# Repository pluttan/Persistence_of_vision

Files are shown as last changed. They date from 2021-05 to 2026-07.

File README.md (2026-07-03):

<div align="center">

# POVgram

**Persistence-of-vision LED cube 8x8x8 with a browser-based 3D animation editor**

</div>

A mechanical platform with a 64-LED WS2812B strip spins on a motor while an ESP32-S2 synchronizes color output with rotation, producing a volumetric 3D image of 512 virtual voxels in mid-air. Animations are created in a browser-based editor and uploaded to the device over Wi-Fi.

## ■ Features

- ❖ **512-voxel 3D display** — 8x8x8 POV cube rendered by a spinning 8x8 LED strip synchronized with a rotation sensor
- ❖ **Browser-based 3D editor** — React app with a Three.js live preview, per-slice pixel painting across XY/YZ/ZX planes, and undo/redo history
- ❖ **Multi-frame animation** — sequences of 8x8x8 frames with configurable rotation speed, looping, per-frame duplication, and drag-and-drop reordering
- ❖ **Custom color palettes** — 16-color palettes (default Catppuccin), saved across sessions via cookies, edited with a native color picker
- ❖ **Wi-Fi upload** — push animations to the device over HTTP as JSON, stored on SPI Flash (FAT), played back on demand
- ❖ **USB Mass Storage** — device appears as a USB drive (TinyUSB MSC) for direct file access to stored animations
- ❖ **PID motor control** — closed-loop speed regulation with hard-kickstart logic and fixed-point slider-crank layer-timing math

## ■ Stack

<div align="center">

| Component | Technology |
|---|---|
| MCU | ESP32-S2 |
| Firmware | ESP-IDF + FreeRTOS (C++) |
| LEDs | 64x WS2812B via SPI DMA |
| Layer timing | GPTimer (us reset) + fixed-point slider-crank math |
| Motor control | PID controller + LEDC PWM |
| Storage | SPI Flash (FAT via TinyUSB MSC) |
| HTTP server | esp_http_server (Wi-Fi STA) |
| Frontend | React 19 + Vite 7 |
| 3D visualization | Three.js (OrbitControls) |
| Default palette | Catppuccin |

</div>

## ■ How It Works

```
1. The rotation sensor fires a rising-edge interrupt; the ESP32-S2 uses fixed-point slider-crank math to compute precise per-layer timing offsets.
2. PID motor control (LEDC PWM) maintains stable rotation speed with hard-kickstart logic.
3. At each computed offset the firmware drives the 8x8 WS2812B strip via SPI DMA, painting one vertical slice of the current animation frame — building the full 8x8x8 voxel volume in mid-air.
4. Animations are authored in the browser editor: frames are painted slice-by-slice on XY/YZ/ZX planes and previewed live in a Three.js 3D view with undo/redo support.
5. The finished animation is exported as JSON and pushed to the device over HTTP (Wi-Fi); the device stores it on SPI Flash (FAT) and plays it back on demand.
6. The same Flash partition is also accessible as a USB Mass Storage drive (TinyUSB MSC) for direct file management.
```

## ■ Screenshots

<div align="center">



*Main animation editor interface with 3D cube preview*

</div>

## ■ Usage

### Frontend (animation editor)

```bash
cd povgram-frontend
npm install
npm run dev
```

### Firmware

```bash
cd usb-example/tusb_msc
idf.py set-target esp32s2
idf.py menuconfig    # set WIFI_SSID and WIFI_PASSWORD
idf.py build flash
```

### Upload Animation

1. Open the web editor in a browser
2. Draw frames slice by slice in the 8x8 grid, preview the cube in 3D
3. Enter the device IP in the badge, then open the Export menu and flash the animation to the device
4. Trigger playback from the same menu to display it on the cube

## ■ Repository Structure

```
POVgram/
├── povgram-frontend/             # React web editor (Vite)
│   └── src/
│       ├── components/
│       │   ├── MagicCube.jsx     # Main orchestrator / layout
│       │   ├── Cube3D/           # Three.js 3D preview
│       │   ├── panels.jsx        # LayerEditor, Palette, FrameTimeline, ExportMenu, ...
│       │   ├── ui.jsx            # Logo, ToolDock, ZNav, DeviceBadge, ...
│       │   ├── VoxelThumb.jsx    # Frame thumbnail renderer
│       │   ├── Onboarding.jsx    # First-run overlay
│       │   └── Toast.jsx         # Toast notifications
│       ├── hooks/
│       │   ├── useFrameAnimation.js  # Frame management + playback + undo/redo
│       │   └── usePaletteSystem.js   # Palette state + persistence
│       └── utils/                # device protocol, palette, voxel, persist
│
├── usb-example/tusb_msc/         # ESP32-S2 firmware (ESP-IDF)
│   └── main/components/
│       ├── init                  # task setup, sensor ISR, drawLayer
│       ├── wifi                  # Wi-Fi STA + HTTP API (esp_http_server)
│       ├── leds                  # WS2812B SPI driver + GPTimer
│       ├── pidController         # Motor speed regulation (PID + LEDC)
│       ├── PointsCalc            # Fixed-point slider-crank layer timing
│       └── usbMscStorage         # USB MSC + FAT filesystem
│
├── esp32c3-render-node/          # Experimental ESP32-C3 24x24x24 render node (SPI slave)
├── esp32c3-test-master/          # Experimental ESP32-C3 SPI-master test bench
└── demos/                        # Sample animations (JSON) + Node.js generators
```

## ■ Hardware

<div align="center">

| Part | Description |
|---|---|
| MCU | ESP32-S2 |
| LEDs | 64x WS2812B strip (data on GPIO 16, SPI2 @ 2.5 MHz) |
| Motor | DC motor + driver (LEDC PWM on GPIO 40, 2 kHz) |
| Sensor | Rotation sensor (GPIO 39, rising-edge interrupt, internal pull-up) |
| Storage | Internal SPI Flash (1 MB FAT partition) |
| Interface | USB (Mass Storage) + Wi-Fi (HTTP API) |

</div>

## ■ License

MIT © [pluttan](https://github.com/pluttan)

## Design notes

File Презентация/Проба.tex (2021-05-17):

\documentclass[10pt,pdf,hyperref={unicode}]{beamer}
\usepackage[T2A]{fontenc}
\usepackage[utf8]{inputenc}
\usepackage{movie15}
\setbeamertemplate{navigation symbols}{}
\usetheme{default}
\setbeamertemplate{background}{}

\definecolor{UniBlue}{RGB}{183,221,255}
\setbeamercolor{title}{fg=UniBlue}
\setbeamercolor{frametitle}{fg=UniBlue}
\setbeamercolor{structure}{fg=UniBlue}
\setbeamercolor{normal text}{fg=white}

\title{The title of presentation}   
\subtitle{Use beamer everywhere you are}
\begin{document}

\begin{frame}
\include{title}
\end{frame} 

\begin{frame}
\includemovie{1cm}{1cm}{ani.gif}
\end{frame}

\end{document}

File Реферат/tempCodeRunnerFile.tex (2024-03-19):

\vspace*{200px}
  \begin{flushright}
    Выполнил ученик 10 «А» класса\\
    Плютто Андрей Петрович\\
    Руководитель проекта\\
    учитель физики\\
    Горцакалян Жанна Степановна\\
  \end{flushright}

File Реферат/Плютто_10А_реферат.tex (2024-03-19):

\documentclass[a4paper, 12pt]{article}
\usepackage[T2A]{fontenc}
\usepackage[left=2cm,right=2cm,top=2cm,bottom=2cm]{geometry}
\usepackage[russian]{babel}
\usepackage{amsfonts,amsmath,amssymb}
\usepackage{mathrsfs}
\usepackage{graphicx}
\usepackage[normalem]{ulem}
\usepackage{wrapfig}
\usepackage{fancyhdr}
\usepackage{floatflt}
\usepackage{python}
\usepackage{indentfirst}
\usepackage{setspace}
\usepackage{scrextend}
\usepackage{listings}
\usepackage{makecell,tabularx}
\usepackage{hyperref}
\usepackage{xcolor}

\newcommand{\rub}{{\rm{Р}\kern-.635em\rule[.5ex]{.52em}{.04em}\kern.11em}}

\definecolor{linkcolor}{HTML}{000000} 
\definecolor{urlcolor}{HTML}{0000FF} 

\hypersetup{pdfstartview=FitH,  linkcolor=linkcolor,urlcolor=urlcolor, colorlinks=true}

\definecolor{grey}{RGB}{40, 40, 40}

\renewcommand{\href}[1]{\url{#1}}

\lstdefinestyle{CommentStyle}{
    language=XML,
    %numbers=left, numberstyle=\tiny, stepnumber=1, numbersep=5pt,
    commentstyle=\color{red},
	basicstyle=\footnotesize\ttfamily,
	language={[ANSI]C++},
	keywordstyle=\bfseries,
	showstringspaces=false,
	morekeywords={include, printf},
	commentstyle={},
	escapeinside=§§,
	escapebegin=\begin{russian}\commentfont,
	escapeend=\end{russian},
    keywordstyle=\color{blue}\bfseries,
    morekeywords={align,begin},
    extendedchars=\true,
    tabsize=2
}
\lstdefinestyle{myLatexStyle}{
    language=c++,
    %backgroundcolor=\color{grey},
    numbers=left, numberstyle=\tiny, stepnumber=1, numbersep=5pt,
    commentstyle=\color{red},
    keywordstyle=\color{blue}\bfseries,
    morekeywords={align,begin},
    extendedchars=\true,
    tabsize=2
}

\lstdefinestyle{pmyLatexStyle}{
    language=java,
    %backgroundcolor=\color{grey},
    numbers=left, numberstyle=\tiny, stepnumber=1, numbersep=5pt,
    commentstyle=\color{red},
    keywordstyle=\color{blue}\bfseries,
    morekeywords={align,begin},
    extendedchars=\true,
    tabsize=2
}

\setlength{\parindent}{12,5mm}

\onehalfspacing

\pagestyle{fancy}
\renewcommand{\sectionmark}[1]{\markright{#1}}
\fancyhf{} 
\fancyhead[R]{\bfseries\thepage}
\fancyhead[LO]{\bfseries\rightmark}

\newcommand{\image}[3]{
	\begin{figure}[ht]
		\center{ }
		\caption{\textit{#3}}\end{figure}
}
%\title{Проектная работа по теме:«Персистенция в реальной жизни»}

\newcommand{\cmd}[1]{\immediate\write18{#1}}
\newcommand{\pf}[1]{\immediate\input{#1}}
% \newcommand{\n}{ }
% \newcommand{\py}[1]{
% 	\cmd{
% 		k=''&&py=${k}&&n='exec("""def vip(l,k):\\n    for i in range(len(l)):\\n        try:\\n            if l[i]==";":i,k=i+1,k+("\\\\n")\\n            else: k+=l[i]\\n        except:break\\n    exec(k)\\n""");vip("""#1""".replace("|",chr(32)).replace(";"+chr(32),";"),"")'&&printf ${n// /|}>latex.py
% 		}
% 	\cmd{
% 		python3 latex.py>py.out 2>py.log
% 		}
% 	\pf{
% 		py.out
% 	   }
% 	}

\begin{document}
\thispagestyle{empty}
\begin{floatingfigure}{5.8cm}
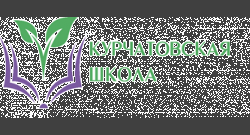
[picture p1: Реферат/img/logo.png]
  
  \vspace{0cm}
\end{floatingfigure}

\sloppy{
  \scriptsize{
    \line(6,0){0}

    \centering Департамент образования и науки города Москвы

    \centering ГОСУДАРСТВЕННОЕ БЮДЖЕТНОЕ

    \centering ОБЩЕОБРАЗОВАТЕЛЬНОЕ УЧРЕЖДЕНИЕ ГОРОДА

    \centering МОСКВЫ «КУРЧАТОВСКАЯ ШКОЛА»

    \line(6,0){300}

    \centering 123060, Москва, улица Маршала Конева, дом 10.

    \centering \textbf{Тел: (499) 194-10-44, E-mail: kurchat@edu.mos.ru}

    \line(6,0){0}
  }}

\topskip=-200pt
\vspace*{130px}
\begin{Huge}
  \textbf{
    \begin{center}
      Проектная работа по теме:\\«Персистенция в реальной жизни»
    \end{center}
  }
\end{Huge}
\vspace*{5px}
\begin{footnotesize}
  \center {В проекте был рассмотрен эффект персистенции зрения на примере сложного трехмерного опыта.
    В результате опыта получился один из видов голограмм: светодиодная голограмма.
    В рамках проекта также можно найти объяснение, применение и историю эффекта. }
  \vspace*{200px}
  \begin{flushright}
    Выполнил ученик 10 «А» класса\\
    Плютто Андрей Петрович\\
    Руководитель проекта\\
    учитель физики\\
    Горцакалян Жанна Степановна\\
  \end{flushright}
\end{footnotesize}
\begin{normalsize}
  \begin{center}
    Москва\\
    2021 год
  \end{center}
\end{normalsize}
\newpage
\thispagestyle{fancy}
\renewcommand{\sectionmark}[1]{\markright{#1}}
\fancyhf{}
\fancyhead[R]{\bfseries\thepage}
\fancyhead[LO]{\bfseries Оглавление}
\renewcommand{\contentsname}{Оглавление}
\small{\tableofcontents}
\newpage
\pagestyle{fancy}
\renewcommand{\sectionmark}[1]{\markright{#1}}
\fancyhf{}
\fancyhead[R]{\bfseries\thepage}
\fancyhead[LO]{\bfseries\rightmark}

\section{Аннотация}
Работа «Персистенция в реальной жизни» посвящена эффекту
персистенции зрения, наглядно представленному на примере сложного
трехмерного, иллюстрирующего этот любопытный феномен, опыта.
Понятие «персистенция зрения» (от лат. persisto - постоянно
пребывать, оставаться) иначе можно передать как «инерция зрения»,
многочисленные примеры которой были известны еще древним. Скажем,
если крутить горящий факел, человеческий мозг будет его
воспринимать — видеть — как огненный круг вместо ряда
последовательных положений одного и того же горящего факела,
ходящего по кругу. По сути, речь идет об иллюзии, значимость
которой отмечали еще древнеиндийские философы. Они утверждали,
например, что так называемая «человеческая личность»    - тоже
всего лишь похожий эффект «инерции умозрения». Иллюзия «личности»
видится нами как «единая целостность», как факельный круг, только
потому, что наш умственный взор не силах зафиксировать отдельные
точки движения человеческой души. На этом широком фоне понимания
сути данного эффекта интересно было представить конкретную краткую
историю его научного изучения, а также его объяснение и возможное
применение. Эти задачи выполнены на современном и технически
актуальном примере создания одного из видов голограмм: на примере
POV\footnote{\ POV -- Persistence of vision(персистенция зрения)}-голограммы.
\newpage
\section{Введение}
\subsection{Актуальность}
POV эффект мы можем наблюдать в реальной жизни каждый день.
Достаточно навести камеру телефона на электронные часы,
и мы сразу увидим частоту обновления кадров (FPS\footnote{FPS -- Frame-Per-Second(кадров в секунду)}).
То, что мы не видим это невооруженным глазом, объясняет POV эффект.
Поэтому POV является чуть ли не самым используемым эффектом анатомии человека.
\subsection{Проблема}
Потенциал персистенции зрения еще не раскрыт полностью. С помощью POV можно
создавать моментально не только 2D экраны, но и полноценные 3D голограммы.
\subsection{Цель работы}
Раскрыть потенциал POV, создать собственную голограмму из подручных средств.
\subsection{Задачи}
\begin{enumerate}
  \item Объяснить, как работает эффект
  \item Объяснить историю его открытия, историю его применения в физике
  \item Выяснить где эффект используется в наше время
  \item Создать собственную 3D поделку на основе данного эффекта
\end{enumerate}
\newpage
\section{Общие сведения о инерции зрения}
\subsection{Определение}
Персистенция зрения традиционно относится к оптической иллюзии,
которая возникает, когда зрительное восприятие объекта не прекращается
в течение некоторого времени после того, как исходящие от него лучи света
перестали попадать в глаз. Иллюзия также была описана как
"персистенция сетчатки", "персистенция впечатлений", просто "персистенция"
и другие варианты. Согласно этому определению, иллюзия будет такой же
или очень похожей на позитивные остаточные образы.

С момента своего появления термин "персистенция зрения" считается объяснением
восприятия движения в оптических игрушках, таких как фенакистископ и зоотроп,
а позже и в кино. Однако эта теория была оспорена еще до появления кинематографа
в 1895 году. Если " постоянство зрения "объяснить, как" слияние мерцания", то его
можно рассматривать как фактор иллюзии движущихся картинок в кино и связанных с ним
оптических игрушках, но не как ее единственный принцип.

Наиболее важным фактором в этом типе анимации является стробоскопический эффект,
подробно описанный изобретателем Саймоном Стампфером, но это было в значительной
степени проигнорировано теоретиками кино (по крайней мере, за пределами Германии и Австрии).

Ранние описания иллюзии часто объясняли этот эффект исключительно несовершенством
глаз, особенно сетчатки. Нервы и части мозга позже стали частью объяснений.
\subsection{Почему возникает?}

Эффект возникает при переполнении, перенасыщении палочек глаза.
Дело в том, что наш глаз состоит из палочек и колбочек: колбочки отвечают
за различие цветов, а палочки за насыщенность цвета. Когда цвет в
колбочках перенасыщается уже не можем различать один цвет от другого и
видим их все вместе.

\image{глаз.png}{170}{Строение человеческого глаза}

\newpage

\section{История POV}

Первое упоминание о персистенции зрения сделано Аристотелем
в 384-322 годах до н.э. Он первый отметил, что он наблюдает
солнечные лучи еще некоторое время после того как перестает
смотреть на них.

Открытие эффекта часто приписывают римскому поэту Лукрецию
(ок. 15 октября 99 г. до н. э.-ок. 55 г. до н. э.), хотя он лишь упоминает
нечто подобное в связи с образами, увиденными во сне.

Примерно в 165 году нашей эры Птолемей описал в своей книге
"оптика" вращающийся гончарный круг с нанесенными на него
различными цветами. Он отметил, как различные цвета секторов
смешиваются в один цвет и как точки появляются в виде кругов, когда
колесо вращается очень быстро. Когда линии рисуются поперек оси
диска, они заставляют всю поверхность казаться однородной по цвету.

"За зрительным впечатлением, созданным в первом обороте, неизменно
следуют повторные случаи, которые впоследствии производят
тождественное впечатление. Это также происходит в случае падающих
звезд, чей свет кажется расширенным из-за их скорости движения, все
в соответствии с количеством она проходит на ощутимом расстоянии
вместе с чувственным впечатлением, возникающим в зрительной
способности.

Порфирий (около 243-305) в своем комментарии к гармоникам
Птолемея описывает, что чувства не стабильны, а запутанны и неточны.
Определенные интервалы между повторными впечатлениями не
обнаруживаются. Белое или черное пятно на вращающемся конусе (или
вершине) выглядит как круг этого цвета, а линия на вершине
заставляет всю поверхность выглядеть в этом цвете. "Из-за быстроты
движения мы получаем впечатление линии на каждой части конуса,
когда линия движется."

В XI веке Ибн аль-Хайтам, который был знаком с трудами
Птолемея, описал, как цветные линии на волчке не могли быть
различимы как разные цвета, но появлялись как один новый цвет,
состоящий из всех цветов линий. Он сделал вывод, что зрению нужно
некоторое время, чтобы различить цвет. Аль-Хайтам также отметил,
что вершина казалась неподвижной, когда вращалась чрезвычайно
быстро, "поскольку ни одна из ее точек не оставалась неподвижной в
одном и том же месте в течение какого-либо ощутимого времени".

Леонардо да Винчи писал в своей записной книжке: "каждое тело,
которое движется быстро, кажется окрашивающим свой путь
впечатлением своего оттенка. Истинность этого положения видна из
опыта; так, когда молния движется среди темных облаков, скорость ее
извилистого полета делает весь ее путь похожим на светящуюся змею.

Таким же образом, если вы взмахнете зажженным клеймом, весь его
ход будет казаться кольцом пламени. Это происходит потому, что
орган восприятия действует быстрее, чем суждение."

Исаак Ньютон (1642-1726 / 27) якобы продемонстрировал, как
белый свет представляет собой комбинацию различных цветов с
вращающимся диском с цветными сегментами. При быстром вращении
цвета, кажется, смешиваются и кажутся белыми (или, скорее, не
совсем белым светлым оттенком). В его книге 1704 года оптики он
описал машину с призмами, линзой и большой движущейся гребенкой с
зубьями, вызывающими последовательное проецирование
чередующихся цветов. Если это делалось достаточно быстро, то
чередующиеся цвета уже не воспринимались отдельно, а
воспринимались как белые. Ньютон сравнил его принцип с эффектом
следа бенгальского огня: вращающийся горящий уголь может
выглядеть как круг огня, потому что, как он писал: «ощущение угля в
нескольких местах этого круга остается запечатленным на сенсориуме,
пока уголь снова не вернется в то же самое место.»

\image{круг.png}{200}{Ньютоновский опыт с кругом}
В 1768 году Патрик Д'Арси (1725-1779) сообщил, что он измерил
длительность 0,13 секунды для одного полного вращения горящего
угля, в то время как он рассматривался как полный круг света. Он
зарегистрировал несколько вращений специально построенной машины
в своем саду и в сотрудничестве с наблюдателем, который обладал
превосходным зрением (собственное зрение Д'Арси было повреждено в
результате несчастного случая). Д'Арси подозревал, что
продолжительность может отличаться у разных наблюдателей,
интенсивность света вращающихся объектов, цвета и расстояния
наблюдения. Он планировал дальнейшие эксперименты, чтобы
определить такие возможные различия, но, похоже, никаких
результатов опубликовано не было.

Будучи студентом университета, Джозеф Плато заметил в
некоторых своих ранних экспериментах, что при взгляде с небольшого
расстояния на два концентрических зубчатых колеса, которые быстро
вращаются в противоположных направлениях, создается оптическая
иллюзия неподвижного колеса. Позже он прочитал статью Питера
Марка Роже 1824 года и решил исследовать этот феномен дальше. Он
опубликовал свои выводы в Correspondance Mathématique et Physique
\footnote{\ Correspondance Mathématique et Physique -- Математическое и физическое соответствие}
в 1828 году и 1830 году. В 1829 году плато представил свой тогда еще
неназванный анортоскоп в докторской диссертации Sur quelques
propriétés des impressions produites par la lumière sur l'organe de la vue
\footnote{\ Sur quelques
  propriétés des impressions produites par la lumière sur l'organe de la vue --
  некоторых свойствах, производимых светом на зрение}.

\begin{figure}[ht]
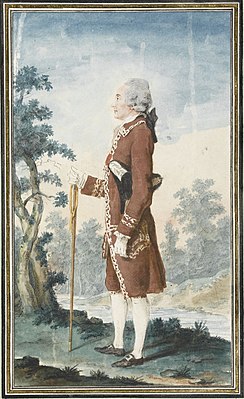
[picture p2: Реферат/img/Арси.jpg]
  \center{
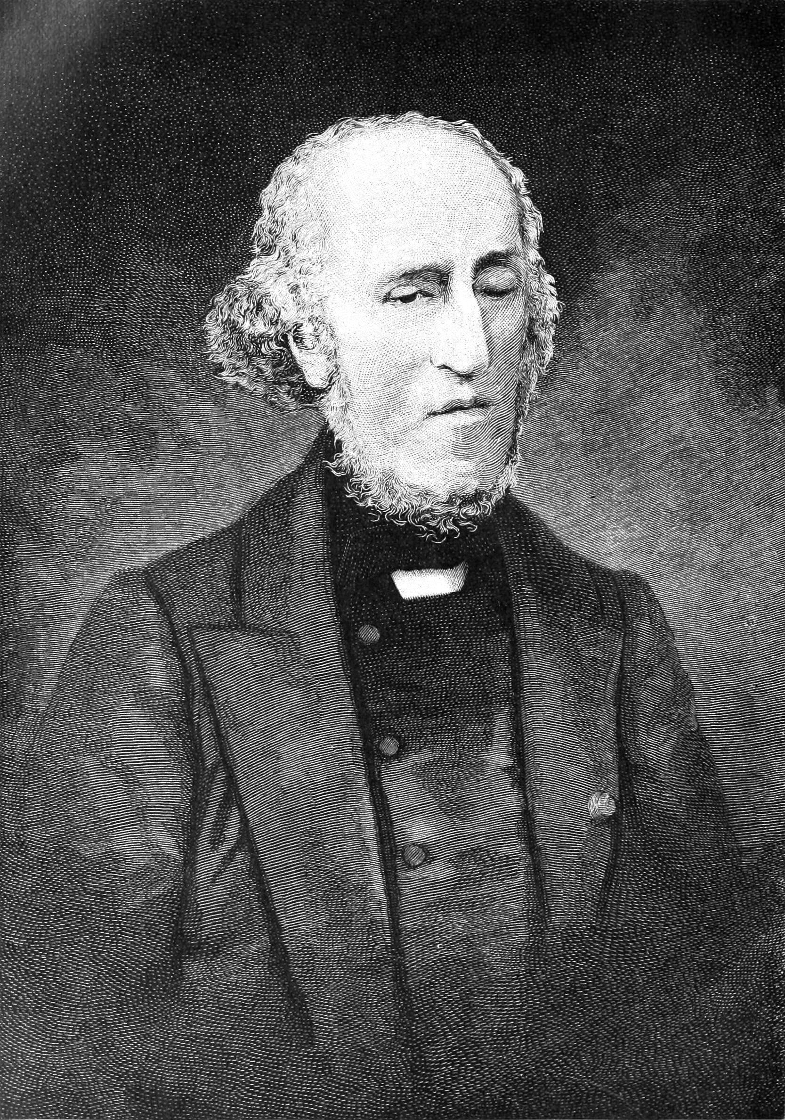
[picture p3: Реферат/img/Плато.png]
    }
  \caption{Слева -- \textit{Патрик Д'Арси}, Справа -- \textit{Джозеф Плато}}
\end{figure}

Анортоскоп представлял собой диск с анаморфным изображением,
которое можно было рассматривать как четкое неподвижное
изображение, когда диск вращался и просматривался через четыре
радиальные щели встречно вращающегося диска. Диски также могли
быть полупрозрачными и освещаться сзади через щели вращающегося
против часовой стрелки диска.

Далее был создан зоотроп, который оказался хорошей заменой
диску, описанному выше. «В зоотропе диск с отверстиями заменен
деревянным или металлическим барабаном, открытым сверху,
прорезанным вертикальными щелями по бокам и вращающимся
горизонтально на оси. Диск с картинками заменен длинной лентой,
которая помещается, свернутая в круг, внутри барабана. Эти ленты
могли вместить пять, десять и более дюжин картинок, тогда как диски
не могли вместить больше двух дюжин.» — Жорж Садуль. Вот мы и
подобрались от истории создания эффекта до использования этого
эффекта в реальной жизни.

\newpage

\section{Природные условия, объясняемые персистенцией}

\subsection{Молния}

При грозе люди обычно видят молнии как большой электрический
разряд из неба. На деле мы чаще всего видим траекторию движения –
остаточное изображение из-за очень яркого белого света.

\image{Гроза.jpg}{200}{След молнии на фоне темного неба}

\subsection{Снежные бури}
В снежную метель иногда становиться сложно увидеть, что
находиться даже в метре от вас. Это возникает не только от того что
одновременно падает огромное количество снежинок, но и от того, что
снежинки преломляют свет, и мы видим свет уже упавших снежинок,
как свет ещё падающих.

\image{Снег.png}{200}{Снежная метель}

\newpage

\section{Прямые использования эффекта}
\subsection{Тауматроп}

Таумотроп - это игрушка, основанная на оптической иллюзии: при
быстром вращении кружка с двумя рисунками, нанесенными с разных сторон,
они воспринимаются как один. Была особо популярна в Викторианскую эпоху.
Жорж Садуль утверждает, что создателем тауматропа является Джон
Гершелл. Ещё в 1824 году он поспорил со своим другом Чарльзом Беббиджем,
что сможет показать ему одновременно две стороны золотой гинеи. Он
вращал монету на ребре, а Беббиджа попросил поместить глаз на её уровне.
Обе стороны монеты слились воедино.

В 1825 Генри Фиттон и доктор Пари, популяризируя этот опыт, превратили
его в детскую игрушку, получившую имя тауматроп.

\image{Пингвин.jpg}{220}{Таумотроп с пингвином в шаре}

\subsection{Анортоскоп}

Анортоскоп — аппарат изобретённый в 1828 году брюссельским
физиком Жозефом Плато.

Анортоскоп состоял из двух дисков: прозрачного, помещённого сзади, и
непрозрачного помещённого впереди и имевшего отверстия. Оси дисков,
находились рядом, но не совпадали и которые приводились во вращение
вокруг одной и той же оси, во взаимно противоположном друг другу
направлении и с различными скоростями. Передний непрозрачный круг
снабжен вырезами, на заднем же, прозрачном и освещаемом помещенной
позади его свечкой, находится рисунок, который, будучи наблюдаем сквозь
щели переднего круга во время вращения кругов, появляется при известном
отношении скоростей вращения обоих кругов.

Анортоскоп создавал впечатление, как говорил Плато: «точного изображения
гиперболы, проходящей через два центра вращения». Позже он заменял одну
из линий рисунками, таким образом получая искаженное изображение вместо
правильной линии.

\image{С мышкой.jpg}{200}{Анортскоп, вышитый 13-летним мальчиком для школьного проекта}

\thispagestyle{fancy}
\renewcommand{\sectionmark}[1]{\markright{#1}}
\fancyhf{}
\fancyhead[R]{\bfseries\thepage}
\fancyhead[LO]{\bfseries Прямые использования эффекта}
\subsection{Фенакистископ и стробоскоп}
Фенакистископ — лабораторный прибор, конструкция которого
основана на персистенции, способности сетчатки человеческого глаза
сохранять изображения. Изобретателем фенакистископа является Жозеф
Плато. Почти одновременно с Плато Симон фон Штампфер изобрел аппарат,
очень похожий на фенакистископ и назвал его «стробоскопом». Является
более совершенным анортоскопом.

\image{Фенакистископ.jpg}{220}{Обычный фенакистископ}

\subsection{Зоотроп}
Я уже упоминал зоотроп в истории создания персистенции, так что
пришло время рассмотреть это подробнее.

Зоотроп — устройство, конструкция которого основана на персистенции,
способности сетчатки человеческого глаза сохранять изображения.

Изобретателем зоотропа является Уильям Джордж Хорнер. Зоотроп является
трансформацией фенакистископа Жозефа Плато.

Современный зоотроп был изобретен в 1833 году британским математиком
Уильямом Джорджем Хорнером. Сам он назвал свое изобретение «дедалеум»
или «колесо дьявола». В 1860 году француз Дезвинь, и американец Уильяма Е.
Линкольн закрепили за всеми подобными устройствами название «зоотропа».

В 2008 году компания Sony создала зоотроп в виде тора диаметром 10 метров
и 10 тонн весом. Внутри находится второй тор, представляющий собой
большое количество выгнутых экранов. Внутренний тор вращается с
окружной скоростью 44 км/ч (и может разгоняться свыше 50 км/ч). На экранах
же появляется высокочёткое изображение.

Зоотроп был занесён в книгу рекордов Гиннесса, как самый крупный в мире.
(Посмотреть на него можно будет в презентации)

\image{зоотроп.jpg}{250}{Чертеж одного из первых зоотропов в мире}

\newpage

\subsection{Кинеограф}

Кинеограф— приспособление для создания анимированного
изображения, состоящего из отдельных кадров, нанесённых на листы бумаги,
сшитые в тетрадь. Зритель, перелистывая особым способом тетрадь,
наблюдает эффект анимации. Кинеография является одной из форм
мультипликации.

Название кинеограф запатентовано в 1868 году англичанином по имени Джон
Бернс Линнет. В 1894 году пионер кинематографа Макс Складановски
использует кинеограф для просмотра своих первых пробных съёмок.

В 1897 году англичанин Генри Уильям Шорт наладил массовое производство
кинеографа под патентованным названием филиоскоп, снабдив его
металлическим футляром и рычагом, облегчающим перелистывание страниц.

\image{Кинеограф.jpg}{300}{Нарисованный кинеограф}

\subsection{GIF}

GIF — растровый формат графических изображений. Способен хранить
сжатые данные без потери качества в формате не более 256 цветов. Не
зависящий от аппаратного обеспечения формат GIF был разработан в 1987
году (GIF87a) в фирме CompuServe для передачи растровых изображений по
сетям. В 1989-м формат был модифицирован (GIF89a): были добавлены
поддержка прозрачности и анимации). Долгое время GIF был одним из
наиболее распространённых форматов в интернете. GIF позволяет соединять
и демонстрировать в виде видео отдельные фотографии.
\newpage
\section{Косвенные использования эффекта}
\pagestyle{fancy}
\renewcommand{\sectionmark}[1]{\markright{#1}}
\fancyhf{}
\fancyhead[R]{\bfseries\thepage}
\fancyhead[LO]{\bfseries\rightmark}

\subsection{Кадровая частота}

Кадровая частота используется в абсолютно всех экранах и мониторах,
это специальная величина которая измеряет сколько кадров монитор покажет
в секунду. Когда монитор показывает много кадров мы видим целое, не
склеенное видео. Тут инерция зрения возникает как косвенный эффект. Как
интересный факт стоит отметить то что до 1922 года инерция зрения
считалась основным эффектом зрения, который используют в фильмах, но
затем было доказано обратное.

\image{Медведь.jpg}{80}{Один шаг анимированного медведя (покадрово)}

Дополнительные примеры: Электронные часы, электронные
билборды, видео.

\subsection{POV пропеллер}

И вот мы подобрались к самому интересному: POV механизмы. Каждый
из нас замечал на детских праздниках светящиеся пропеллеры. Они состоят
из простого мотора и нескольких светодиодов. Дело в том, что если
посмотреть на этот пропеллер со стороны науки, то он опережает свое время.
Он не только дает красивый зрительный эффект, но и преображает
одномерную полоску светодиодов в двумерный рисунок. Впоследствии
именно это стало отправной точкой моего продукта.

\image{пропеллер.jpg}{200}{POV пропеллер}

\newpage

\section{Практическая часть}
\vspace{-7px}
\subsection{Введение в практическую часть}

Любой проект начинается с идеи. Мой проект тоже начался с идеи.
Точнее с одной идеи и огромного количества предположений по возможной реализации продукта.
Что-бы как-то объединить все соображения в один продукт я набросал список, того,
что понадобится для физической реализации голограммы:
\vspace{-7px}
\begin{enumerate}
  \item Кривошипно-шатунный механизм
        \vspace{-10px}
  \item Мотор
        \vspace{-10px}
  \item Светодиоды
        \vspace{-10px}
  \item Управление системой
        \vspace{-10px}
\end{enumerate}
\subsubsection{Кривошипно-шатунный механизм}

Кривошипно-шатунный механизм(КШМ) предназначен для преобразования
возвратно-поступательного движения поршня во вращательное движение
(например, во вращательное движение коленчатого вала в двигателях
внутреннего сгорания), и наоборот. Детали КШМ делят на две
группы, это подвижные и неподвижные детали:

Подвижные: поршень с поршневыми кольцами, поршневой палец,
шатун, коленчатый вал с подшипниками или кривошип, маховик.

Неподвижные: блок цилиндров (является базовой деталью двигателя
внутреннего сгорания) и представляет собой общую отливку с картером,
головка цилиндров, картер маховика и сцепления, нижний картер (поддон),
гильзы цилиндров, крышки блока, крепежные детали, прокладки крышек
блока, кронштейны, полукольца коленчатого вала.

Конечно это общее определение и устройства КШМ. Мне КШМ нужен для того,
чтобы привести платформу со светодиодами в движение.

\image{Шатун.png}{230}{Устройство КШМ}

\newpage

На Рис.13 изображена примерная модель моего шатунного механизма
Как видно он состоит из 4 деталей:
\vspace{-7px}
\begin{enumerate}
  \item Крепление 1 шатуна к мотору
        \vspace{-10px}
  \item 1 шатун
        \vspace{-10px}
  \item 2 шатун
        \vspace{-10px}
  \item Крепление 2 шатуна к платформе
        \vspace{-10px}
\end{enumerate}
Точками BMT и НМТ обозначены самое высокое
положение платформы и самое низкое соответственно.
Между ними расстояние S к которое я вычислю позже.
Шатунный механизм получилось сделать достаточно просто
из маленького кусочка орг-стекла и пару отрезков проволоки.

\subsubsection{Мотор}

Понятно, что шатунный механизм надо привести в движение
при помощи мотора.
Сначала я подумал реализовать мотор без каких-либо затрат,
с помощью дрели и крепежей, но затем я нашел неплохой вариант
мотора из СССР.

\image{Мотор.jpg}{250}{Мотор}

Крутящиеся части у него с 2 сторон, поэтому можно сделать целых 2 шатунных механизма
с одной и другой стороны. Питание может происходить от розетки без адаптеров питания.
В начале проекта это было довольно удобным дополнением, но затем пришлось помучаться
(см. 8.4.3).

\newpage
\subsubsection{Светодиоды}

Светодиоды -- самая главная часть моего продукта
изначально идея заключалась в том, чтобы сделать маленькую
матрицу из RGB\footnote{\ RGB -- red green blue(красный зеленый синий)} светодиодов.

\image{Светодиод.png}{140}{RGB светодиод}

На картинке видно, что у каждого светодиода есть 4 ножки. Если на первую подать
плюс а на вторую минус, то загорится красный цвет. Если на третью подать
плюс а на вторую минус, то загорится зеленый цвет. Если на четвертую подать
плюс а на вторую минус, то загорится синий цвет.

\begin{figure}[ht]
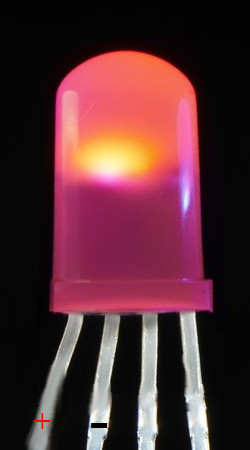
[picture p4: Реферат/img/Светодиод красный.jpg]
  \center{ }
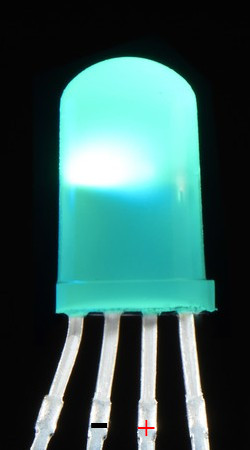
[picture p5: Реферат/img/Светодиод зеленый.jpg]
  
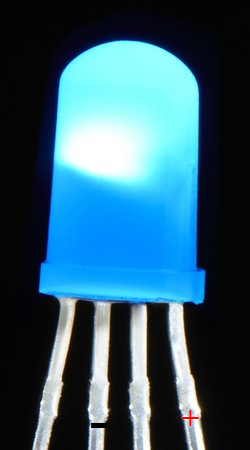
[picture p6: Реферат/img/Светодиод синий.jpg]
  
  \caption{\textit{RGB светодиод, горящий красным, зеленым и синим цветом}}
\end{figure}

И так теперь у нас есть 3 цвета: красный, зеленый, синий.
Теперь смешаем цвета: из красного и синего получим фиолетовый,
из красного и зеленого -- желтый, из зеленого и синего -- голубой.
Если соединим все три ножки, то получим белый.
И так у нас есть практически вся палитра радуги(за исключением оранжевого)
и белый цвет. При всех этих обстоятельствах я подавал ток с фиксированным напряжением
3V. Но производители заявляют, что на RGB светодиоды можно подать от 2,1V до 3,3V но
как можно было догадаться если мы будем подавать ток с меньшим напряжением, то светодиоды
будут гореть тускло, а с большим ярко. В аналоговых входах моего МК
\footnote{\ МК -- микроконтроллер(подробнее в 8.1.4)}
напряжение можно подавать деля его на десятые. Таким образом получаем, что у
нас есть есть 23 напряжения и 7 цветов для каждого напряжения. Вычислим
количество цветов и оттенков К, которые мы можем получить $$K=23!\times
  7\thickapprox 1,8*10^{23}$$ Конечно мы не увидим каждый из оттенков и они нам
попросту не нужны в настолько большом сегменте. Возьмем общепринятое количество
оттенков каждого цвета -- 256. Тогда для того, что-бы запрограммировать 1
светодиод нам понадобится передать коду L значений. Вычислим L: $$L=256\times
  256\times 256= 16777216 \thickapprox 1,6*10^7$$ Ученые-биологи пока доказали,
что человек может воспринимать около 10 миллионов ($10^7$) цветов, поэтому для
школьного проекта такой палитры цветов будет более чем достаточно.

Это все начальные данные о светодиодах, которые необходимо знать не только для
того,чтобы понять, но и для того, чтобы повторить проект.

\subsubsection{Микроконтроллер}

Из текста о светодиодах можно было понять, что для управления ими нужен
источник питания источником питания может служить простой адаптер для зарядки
гаджетов, но тогда, что-бы включить или выключить светодиод нам придется
совершать определенные механические действия. Но человечество давно изобрело
процессоры, которые помогают из несложного набора единиц и нулей начать или
прекратить подачу энергии на определенные участки пути. Конечно, использовать
голый процессор в моем проекте было бы сложно и не очень нужно: ведь процессору
нужна и память, и программатор, и ядро, написание которого может занять годы.

Поэтому предлагаю вашему вниманию список, состоящий из названий микросхем в
корпусе которых это объединено:

\begin{enumerate}
  \item   Микрокомпьютер
  \item   Компьютер
  \item   Микроконтроллер (МК)
\end{enumerate}

Давайте поподробнее разберем все 3 варианта и в конце, сопоставив все, выберем
самый лучший. Для этого я составил таблицу, которая показывает 3 главных
аспекта: кол-во портов, память и удобство программировать.
\begin{center}
  \begin{small}
    \begin{tabular}{ |c|c|c|c|c|}
      \hline
      Название   & Определение            & Кол-во портов & Память(ГБ) & Программирование        \\ \hline

      Микро-     & Семейство компьютеров, & 12-46         & 8-256      & удобные среды           \\
      компьютер  & которые в отличии      &               &            & разработки              \\
                 & от других компьютеров  &               &            & непосредственно         \\
                 & работают на            &               &            & в микрокомпьютере       \\
                 & RAM-архетиктуры.       &               &            &                         \\ \hline

      Компьютер  & Здесь: система,        & 2-8           & 256-2048   & Практически нету        \\
                 & имеющая полноценный    &               &            & открытых средств        \\
                 & процессор, способный   &               &            & разработки, все команды \\
                 & выполнять миллиарды    &               &            & по управлению USB       \\
                 & операций в секунду     &               &            & можно осуществить       \\
                 &                        &               &            & только через терминал   \\\hline

      Микро-     & Микрокомпьютер         & 12-56         & до 1       & среда разработки        \\
      контроллер & с урезанным            &               &            & Arduino idle            \\
                 & функцианалом           &               &            &                         \\
      \hline
    \end{tabular}
  \end{small}
\end{center}
Давайте разберемся по порядку: я беру микроконтроллер для удобства его
программирования также у него должно быть достаточное кол-во портов для
подключения всей электроники, о которой речь пойдет позже, так что компьютер,
не смотря на его большую вычислительную мощность не подходит.

Так же мне ни к чему покупать микрокомпьютер т.к. с таким проектом может
справится сравнительно небольшой микроконтроллер. На нем я и остановился, а
именно на модели Arduino NANO.

\image{дуня нано2.jpg}{140}{Arduino NANO}

Пусть на такой микроконтроллер провода нужно будет припаивать, но по моему
опыту это один из самых удобных МК из всех. Так же следует отметить, что
Arduino NANO - уменьшаная копия Arduino UNO, так что в последствии я буду
использовать обе модели для наглядности, разницы между ними нет. На Рис. 17
представлена распиновка (последовательность входов и выходов МК). Стоит
отметить, что даже на таком маленьком микроконтроллере я не использую все
выходы, а лишь несколько цифровых (помеченных надписью Dig).

\image{дуня нано.jpg}{150}{Распиновка Arduino NANO}

\subsubsection{Светодиодная матрица}

А теперь перейдем к решению вопроса, который я старательно обходил в 8.1.3:
если у светодиода 4 ножки, то ему понадобится 4 пина?

Да это так, а т.к. мой продукт должен состоять не из одного светодиода, а
как минимум 4, то их ножки займут все 12 цифровых выходов(+) и 1 землю(-).
Но голограмма 4$\times$4$\times$4 будет слишком маленькой. В идеале размеры
голограммы должны составлять 16$\times$16$\times$16. Но тогда ножек у
светодиодов будет $16*16*3=768$, что в 64 раза больше, чем есть у меня на
плате, и в 15 раз больше, чем на самом большом МК, который подается сегодня.

Рассмотри RGB ленту:Начнем с того, что в обычной светодиодной ленте, все светодиоды ленты
питаются и светятся одновременно, поскольку все они получают питание
параллельно от одного источника, драйвера, который работает по своему алгоритму, реализуемому
непосредственно внутри драйвера, и просто подает питание сразу на всю ленту, по сути - на все
параллельно подключенные к нему светодиоды.

Адресная светодиодная лента, в отличие от обычной, содержит так называемые адресные
светодиоды. Это значит, что каждый светодиод хотя и получает питание параллельно от
общего источника, включается каждый светодиод по индивидуальной команде, и значит,
на каждом светодиоде можно получить собственный уникальный оттенок, один из 16581375
возможных(см.8.1.3).

Каждый светодиод в адресной ленте имеет свой уникальный адрес, по которому
драйвер обращается к нему при помощи трехбитной команды. Команды отправляются в
линию последовательно, для этого служит третий на ленте провод «DATA INPUT».

\image{лента.jpg}{80}{Распиновка адресной ленты}

Возле каждого светодиода на адресной ленте установлен свой микрочип.
Каждый чип имеет три выхода — каждый на свой цвет, вход передачи данных,
выход передачи данных, вывод питания, вход установки режима и общий вывод.

Каждый RGB-светодиод на самом деле имеет в себе три светодиода (красный,
зеленый и синий), поэтому для управления одним сегментом (один сегмент — это
RGB-светодиод с чипом) требуется 3 байта информации, один байт — один цвет.

Каждый байт может принимать одно из 255 значений, поэтому в принципе каждый
RGB-светодиод способен дать свет одним из 16581375 оттенков. Количество байт
в одной команде равно таким образом 3 умножить на количество последовательных
рабочих сегментов в ленте. Конечно можно передавать ленте каждый раз по 3
значения, но я думаю, что удобнее всего будет передать ей один цвет в формате
hex(16-битный формат представления цвета, где каждый цвет кодируется 2
символами).

%Но как можно было понять что-бы сделать из ленты матрицу надо разрубить 256
%светодиодную ленту на 16 кусочков по 16 светодиодов, а затем соединить их
%последовательно.

\image{лента в тинкеркад.png}{180}{Макет адресной марицы, созданный мной}

\newpage

\subsection{Корпус}
И так мы определили все, что нужно для реализации продукта.
теперь надо подумать как это все компактно уместить под крышку
одного корпуса.
\subsubsection{Размеры}
Конечно сначала нужно поговорить о размерах корпуса,ведь принцип
чем больше - тем лучше я думаю не подходит. И так структурируем каждую
деталь корпуса. Стоит отметить, что под корпусом я подразумеваю только
неподвижные детали, о шатунном механизме, моторе и других деталях я
напишу позже.

Хочется отметить, что на этот момент у меня уже есть все вещи, которые описаны
в 8.1, поэтому я могу совершенно спокойно снять все замеры именно с них.
Внимательно изучив все полученные данные я понял, что платформа, на которую
будет крепится сама модель должна быть размером 16$\times$22, что-бы на ней
поместилась матрица и дополнительные крепления. К слову матрицу я сделал не
сам, как первоначально задумывал, а купил в китае, т.к. цена на ленту с таким
же количеством светодиодов была даже выше, чем цена на матрицу(подробнее 8.8.3)

Далее изучив размер мотора, я понял, что коробка корпуса должна быть высотой в
20см. Таким образом я набросал примерный план некоторых деталей для статической
части корпуса.
\\
\begin{center}
  \begin{tabular}{ |c|c|c|c|c|}
    \hline
    Номер  & Количество & Материал & Размеры(мм)             \\
    детали & деталей    &          &                         \\
    \hline
    1      & 2          & фанера   & 220$\times$200$\times$5 \\
    \hline
    2      & 3          & фанера   & 160$\times$200$\times$5 \\
    \hline
    3      & 4          & брус     & 20$\times$200$\times$10 \\
    \hline
    4      & 4          & стальной & 320$\times$8            \\
           &            & стержень &                         \\
    \hline
  \end{tabular}
\end{center}

\newpage
\subsubsection{Детали 1-2}

Первые две детали будут образовывать коробку, в которой будет находится
электроника и шатунный механизм. Вы, наверное, заметили, что вторых деталей
я сделал в количестве трех штук. Я сделал их именно столько для использования
внутренней перегородки о которой я рассажу позже. Изначально я хотел сделать
эти детали из гипсокартона. Но он оказался слишком рассыпчатый и я решил
выбрать другой материал. В качестве другого материала я взял хороший лист
фанеры и наметил все 5 деталей.

\image{разметка фанеры.jpg}{200}{Разметка фанеры}

Потом начался процесс выпилки. Пилить такое дерево можно практически абсолютно
всем начиная от фрезы заканчивая ручной пилой.Я выбрал относительно легкий
вариант -- электролобзик. Им достаточно легко пилить и получается относительно
маленькая погрешность: всего 0,3мм. Выпилил я все за один зимний вечер и
получилось все с первого раза.

\image{разметка фанеры.jpg}{200}{Выпиленные детали}

\newpage
Дальше начался процесс сборки. Он состоял в том, что надо было разметить  Он был
относительно сложным, т.к фанера имела маленькую ширину.
При вворачивании очередного самореза фанера сломалась. Тогда
я понял, что нужно все переделывать и делать дополнительные подпорки для
каждого угла фанеры.

\subsubsection{Дополнительные подпорки (3-я деталь)}

Для изготовления подпорок я выбрал брус, длиной 2 метра, который я распилил
на 4 кусочка по 20см каждый. Затем я соединил их с 4-ыми деталями и вот, что
получилось:

Конечно можно было мучиться с уголками, но брус выполнял еще одну немаловажную
роль для продукта -- в нем можно было установить держатели для подложки.

\subsubsection{Держатель подложки (4-я деталь)}

Чем я и занялся. Дело в том, что прутья, которые я хотел купить не продают
настолько маленьких размеров, так что за идеально ровными прутьями мне пришлось
ехать на другой конец города -- на металлолом.

Но как можно видеть на фото из этого вытекает целых 2 проблемы: первая, что
прут покрыт ржавчиной, вторая, что он один и большой -- значит прийдется
пилить.

С первой проблемой справился довольно быстро: воду и перекись смешиваем в
пропорции $\frac{2}{1}$ и добавляем лимонную кислоту 100 грамм на 200 мл
перекиси. Оставляем так на час и ржавчины нет.

Со второй проблемой пришлось помучаться: сталь плохо пилится ручной пилой,
а пилы по железу для лобзика у меня нету. В начале я распилил прут на 4 части
по 32 см, но затем оказалось, что это слишком много и прут пришлось подпиливать
после установки.

\subsubsection{Сборка}

Сборка прошла на удивление гладко, в два этапа.

В первый этап я просверлил отверстие в детали 3 диаметром 8 мм, затем
начал забивать деталь 4 в деталь три.

\image{Одна деталь.jpg}{160}{Деталь 4 в детали 3}
\newpage

Далее я повторил свю эту операцию еще три раза. Самое сложное было просверлить
отверстие идеально ровно под углом $90^{\circ}$.

\image{4 детали.jpg}{250}{4 готовых детали}
Осталось прикрутить все вместе. Вот полученный результат:

\image{Получившаяся_конструкция.jpg}{230}{Результат}
\newpage

\subsection{Динамические детали корпуса}

После моего долгого повествования о том, как было сложно сделать корпус
поговорим о еще более важных вещах: закрепление мотора на его месте, пайка
всех проводов и закрепление распределительной коробки рядом с мотором.

Думаю, что для вас это покажется самой скучной часть из всего моего
повествования, так что постараюсь уменьшить ее.

\subsubsection{Мотор}

Для мотора была подготовлена деталь и я подробно рассказывал о её изготовке
в главе 8.2.2. Сама деталь технически представляет собой пятую стенку, которая
разделит уже имеющееся пространство в коробке на 2 параллелепипеда.

В ней я проделал большую дырку и вставил туда мотор. Закрепил его 2 стержнями
горячего клея и прикрутил 4 уголка.

Далее, наметив место для уголков, я закрепил панель в корпусе, предварительно
подняв на нужную высоту.

\subsubsection{Панель и пол}

Панель я решил сделать из оргалита\footnote{прессованный картон, ДВП}.
Получилось даже аккуратно. После я купил линейные подшипники и сделал 4 дырки
для них.

После я сделал небольшую подставку под оптический датчик и пол для закрепления
распределительной коробки.
\subsubsection{Шатун}

Немного посоветовавшись с руководителем моего проекта я понял , что меньший
шатун должен быть 80мм, а наибольший 140мм. Делать шатуны я решил из орк-стекла
с запасом в 10мм. Я взял болты диаметром 3мм и, сделав из металлического листа
держатель, закрепил шатун на его месте.

\subsubsection{Распределительная коробка}

В распределительной коробке я решил сделать ардуино и все провода, ведущие и
исходящие из неё. Но, принявшись за дело, я решил, что к коробке будет трудно
подобраться после склейки корпуса, так что я впаял туда еще ардуино и
аккумулятор.

Вместе с аккумулятором пришлось добавить переключатель и плату для зарядки
аккумулятора.

После я закончил пайку и залил все горячим клеем, который выступил в роли
диэлектрика.

После собрал все в одну коробку и предлагаю вам ознакомиться с доп.
улучшениями, которые я сделал для следующих версий. Хоть в программировании я
это не описал, но все улучшения я подключил и запрограммировал.

\subsection{Дополнительные технические улучшения}

\subsubsection{Щелевой оптический датчик}

Конечно многие могли заметить то, что я избегаю сложных вычислительных
задач в этом проекте и не очень хочу заниматься некоторыми расчетами. Это все
верно, но с помощью оптического датчика можно решить достаточно много проблем
которые могут возникнуть при работе с проектом. Во-первых неравномерность
шатунного механизма. Нетрудно догадаться, что под силой притяжения шатун будет
быстрее спускаться, чем подниматься. Во-вторых могут возникнуть проблемы
в прорисовке и картинка будет сбиваться. В-третьих вычислительная мощность МК
маленькая и все ОЗУ во время прорисовки будет заполнено, так что решать
проблему путем физических вычислений по любому не получится. Тут на помощь
приходит датчик движения. Но не простой. Дело в том, что скорость передачи
датчиков очень мала. Она мала настолько, что просто не возможно что-либо
передать МК на больших скоростях, которые я планирую развить. Поэтому я буду
использовать щелевой датчик движения(щелевой оптический датчик) из названия
которого можно понять, что радиус его поля всего лишь щель.

В данный датчик состоит из лазера и фотоэлектрического датчика: лазер постоянно
светит через через щель, а фотоэлектрический датчик принимает его свет и
выдает нули, если фотоэлектрический датчик перестает принимать свет т.е. между
ним и лазером возникает препятствие, то датчик передает единицы. В нашем случае
препятствие -- нижнее положение шатуна. Таким незамысловатым образом я могу
где находится шатун в определенный промежуток времени.

\image{Датчик.jpg}{130}{Датчик, спаянный и закрепленный на платформе}

\newpage
\subsubsection{Светодиоды}

Для понимания состояния МК я решил добавить на корпус зеленый и желтый
светодиод.\\
\textbf{$\text{Зеленый}$}

Зеленый светодиод я планирую использовать в 2 режимах: первый когда он
горит это означает, что плата работает, прорисовка запущена. Второй когда он
мигает это означает, что плата готовится к запуску. Стоит отметить, что если
светодиод мигает слишком долго -- это означает, что плата не смогла произвести
калибровку и/или возникла ошибка при запуске мотора(см.8.4.3).

\image{Зеленый.jpg}{150}{Зеленый светдодиод}
\textbf{$\text{Желтый}$}

Желтый светодиод будет гореть при всех остальных проблемах и мигать, если будет
загрузка на плату.

\image{Желтый.jpg}{150}{Желтый светодиод}
\newpage

\subsubsection{Реле для мотора}

Реле в моем проекте играет довольно большую роль. Как я говорил в 8.1.2
чтобы связать мотор и МК так, что МК будет управлять мотором нужно реле.

\image{Реле.jpg}{200}{Реле}

Реле -- автоматический переключатель, который может переключить даже маленькая
сила тока. Предлагаю разобраться в его устройстве подробнее:

\image{реле устройство.jpg}{200}{Устройство реле}

Реле представляет собой катушку, состоящую из немагнитного основания, на
которое намотан провод из меди с тканевой или синтетической изоляцией, но чаще
всего с диэлектрическим лаковым покрытием. Внутри катушки установленной на
нетокопроводящее основание, размещается металлический сердечник. Также в
устройстве имеются пружины, якорь, соединительные элементы и пары контактов.

При подаче тока на обмотку электромагнита (соленоида) сердечник притягивает
якорь, который соединяется с контактом и электрическая или электронная цепь
замыкается. При снижении силы тока до определенного значения, якорь, под
действием пружины, возвращается на исходную позицию, вследствие чего
происходит размыкание цепи.

Более плавная и точная работа достигается благодаря использованию резисторов,
а защиту от скачков напряжения и искрения обеспечивает установка конденсаторов.
У большинства электромагнитных реле имеется не одна, а несколько пар
контактов, что позволяет управлять несколькими цепями одновременно.

Далее мы будем говорить о самом важном аспекте моего продукта --
программировании. Но перед тем, как я приступлю рассказывать, я хочу отметить,
что в этой и последующих главах встречается программный код. Оформил я его так:
слева идет код, а справа комментарии и пояснения.

Первым делом я решил запрограммировать матрицу.\newpage
\subsection{Программирование матрицы}
Первый код дался мне довольно легко: всего неделя изучений и улучшений. Предлагаю
вашему вниманию первый рабочий код для светодиодной матрицы.
\begin{flushright}\begin{huge}\textcolor{grey}{Arduino}\end{huge}\end{flushright}
\begin{tabular}{c p{180px}}
  \hline
  \begin{lstlisting}[style=myLatexStyle]
#include "Adafruit_NeoPixel.h"
const uint32_t AR[16][256] PROGMEM = 
#define PIN 13        
#define NUM_LEDS 256   
Adafruit_NeoPixel strip = Adafruit_NeoPixel(
    NUM_LEDS, PIN, NEO_GRB + NEO_KHZ800);
void setup() {
    strip.begin();
    strip.setBrightness(50);    
    strip.clear();                          
    strip.show();                           
	}
void loop() {
    for (int i1 = 0; i1 < 16; i1++){
			for (int i = 0; i < 256; i++){
				strip.setPixelColor(i,
					pgm_read_word(&AR[i1][i]));
				};
			strip.show();
			delay(100);
		};
	}
\end{lstlisting}
   &
  \begin{tabular}{p{180px}}
    Импортируем библиотеку           \\
    Задаем массив данных             \\
    Описываем переменную порта       \\
    Описываем переменную для свет.   \\
    Описываем переменную библиотеки
    на которой управляется матрица   \\
    Начинаем ф-цию установки         \\
    Начинаем общение с матрицей      \\
    Устанавливаем яркость(0-255)     \\
    Очищаем матрицу(заливаем черным) \\
    Показываем результат заливки     \\
    Заканчиваем установку            \\
    Начинаем постоянную ф-цию        \\
    Берем цикл для слоев             \\
    Берем цикл для светодиодов       \\
    Устанавливаем значение
    текущего светодиода              \\
    Заканчиваем цикл светодиодов     \\
    Показываем слой                  \\
    Ждем 100мс                       \\
    Заканчиваем цикл слоев           \\
    Повторяем постоянную ф-цию       \\
  \end{tabular} \\
\end{tabular}

\newpage
\subsubsection{Почему  Adafruit NeoPixel(ст. \#1)}

Для начала предлагаю разобрать все возможные варианты управления матрицами:
через библиотеки и на прямую. Я думаю, что и вам и мне выбор сразу очевиден --
пойти не через библиотеки, т.к. они занимают много ОЗУ и мало для чего будут
нужны. Но тут не все так просто. Пойдя вторым способом я наткнулся на огромное
количество подвисаний с которыми не собирался сталкиваться.

Вывод очевиден: оказывается библеотеки ко всему прочему оптимизируют программу
не давая ей повода зависать. Тут перед нами открывается еще один выбор:
использовать fastLED -- вроде как более универсальную, но новую, не изученную
библиотеку или старую NeoPixel от компании Adafruit. Думаю по моей работе можно
смело заявить, что я не ищу легких путей, поэтому я принялся "грызть"
документацию по fastLED. Но вот прошло некоторое время и наступили каникулы.
Моя семья и я уехали отдыхать и доступа к Arduino у меня не было, но я не
отчаялся и использовал приложение Tinkercad в котором не было матрицы и я её
сделал собственными руками. Результат работы можно посмотреть на Рис. 20.
И тут возникла еще одна проблема: в Tinkercad нету поддержки fastLED, зато
старушка NeoPixel подключается и работает спокойно. Вот так я, перепробовав
кучу вариантов, выбрал самый неочевидный для себя. Под конец программирования
вся среда разработки выглядела так:

\image{Среда.png}{80}{Среда разработки}

\newpage

\subsubsection{Работа с данными (ст. \#2)}

Если вы думали, что тут пойдет лучше -- нет. Оптимальным вариантом был бы
трех мерный массив, но сложность последующего управления им бы зашкаливала,
так что я поставил перед собой задачу использовать одномерный, ну максимум
двумерный массив.

Если вы не совсем понимаете о чем я, ничего сейчас всё объясню. Представим 1
пиксель в качестве куба:

\image{Куб.png}{150}{Один пиксель}

Тогда одна линия ленты -- 16 кубиков.

\image{Линия.png}{150}{Линия пикселей}

Тогда вся матрица -- 16 линий по 16 кубиков.

\image{Матрица.png}{130}{Матрица пикселей}

Но загрузка ленты идет так как она расположена т.е. последовательно, поэтому
можно всю матрицу объединить в ряд, состоящий из 256 кубиков. Каждый кубик
должен иметь свой цвет и даже не горящие светодиоды просто имеют цвет черный.
Тогда можно создать массив цветов, состоящий из 256 значений.
Конечно далее для оптимизации черные точки после перезаливки можно будет
пропускать, но сейчас и так нормально.

Теперь же осталась лишь проблема слоев, которую надо было решать. Ну я пошел
по легкому пути и создал двумерный массив, т.е. массив слоев (16), в каждой
ячейке которого хранится массив цветов.

\image{Куб в кубе.png}{200}{Куб из кубов}

Ну вот и всё подумал я, но все было не так гладко. Для понимания той темы, о
которой я хочу сейчас поговорить я предлагаю посмотреть на строчку из кода:
\begin{lstlisting}[style=myLatexStyle]
const uint32_t AR[16][256] PROGMEM = 
\end{lstlisting}

На деле это просто обрывок, сама она выглядит очень большой, так что вместить
сюда ее тяжеловато и, как я думаю, совсем не нужно. К тому же массив я вставлю,
но чуть позже. Разберемся сначала с левой частью.

Для начала я должен сказать, что AR -- название массива.[16][256] -- описание
всех ячеек. Теперь разберемся с типом. Как я уже упоминал цвет я буду вводить
в hex формате т.е в цифровом формате, но int -- слишком маленький тип для
огромного количества цветов, поэтому предлагаю ознакомиться со всеми доступными
типами данных. Напоминаю, что цветов у нас должно быть 16777216.

\begin{center}
  \begin{tabular}{|l|c|c|c|}
    \hline
    название                & вес   & диапазон                   & работа с   \\
    типа                    & (бит) & значений                   & терминалом \\
    \hline
    int                     & 16    & -32768\dots32767           & Serial     \\
    \hline
    uint                    & 16    & 0\dots65535                & Serial     \\
    \hline
    int32\_t                & 32    & -2147483648\dots2147483647 & Serial     \\
    \hline
    uint32\_t               & 32    & 0\dots4294967295           & Serial     \\
    \hline
    int64\_t                & 64    & $-2^{63}$\dots$2^{63}-1$   & --         \\
    \hline
    uint64\_t               & 64    & 0\dots$2^{64}-1$           & --         \\
    \hline
  \end{tabular}
\end{center}
Как можно заметить int32\_t самый подходящий вариант,но поразмыслив понятно,что
цвет, который мы всегда будем задавать будет величиной положительной, так что
изходя из этого и что-бы легче находить проблем в коде я использовал uint32\_t.

И так, мы определили тип теперь немного теории о памяти: дело в том, что она у
нас ограничена и ОЗУ использовать для такой огромной переменной вообще нельзя.
У меня при загрузке возникла проблема переполнения памяти на 2000\%. Довольно
много. Первая идея у меня, да и наверное у вас: купить дополнительный модуль
памяти, но сейчас этот модуль довольно дорогой и ждать его из китая пришлось
бы долго. Так что будем обходиться средствами МК, немного полазив в интернете,
я понял, что у МК целых 4 памяти: ОЗУ, ПЗУ, PROGMEM, EEPROM. Ну с первыми двумя
все понятно одна оперативная, другая занятая скетчем и ядром. Остаются 2
обе они программируемые, отличие лишь в том, что PROGMEM это расширение для
ОЗУ, а EEPROM - ячеечная память, она имеет 255 ячеек, которые хранят 255
значений, что не достаточно для нас (нужно 256, а это значит, что в одну
ячейку прийдется убрать 16 цветов, что будет не очень удобно и определенно
замедлит процесс прорисовки). Так как в первых версиях я планировал заменять
рисунок путем перезагрузки данных в плату с компьютера, то я подумал, что
сделать эту переменную еще и константой будет хорошей идеей, позже я откажусь
от этого.

\newpage
\subsubsection{Переменная библеотеки (ст.\#3-6)}

Переменная библеотеки strip хранит данные о матрице и о том, что в нее надо
записать. Именно она является неким мостиком между программой и матрицей и
поэтому она просто необходима именно в ОЗУ памяти. Так же я создал
дополнительные переменные PIN и NUM\_LEDS , что-бы было легче ориентироваться в
коде.

\subsubsection{Функция установки (ст.\#7-12)}

Думаю, что эти строчки и по комментариям ясны и  понятны, так что скажу только,
что эта функция выполняется лишь раз при загрузки в плату, далее она не
выполняется.

\subsubsection{Постоянная функция (ст.\#13-22)}

Постоянная функция -- функция, которая, заканчивая свою работу обращается сама
к себе и получается бесконечно рекурентный цикл. в начале этой функции мы
задаем 2 цикла: цикл слоев и цикл света, затем в цикле света рисуем весь слой,
обращаясь к нашей переменной AR с помощью функции для чтения из PROGMEM памяти
pgm\_read\_word(). После окончания рисовки слоя просто выводим его и ждем пару
миллисекунд для прорисовки и рисуем следующий слой.

Вот и вся начальная функция, далее только её обновления и улучшения.

\subsubsection{lines.h или как связать МК и абсолютно любой ЯП}

Понятно,что такой огромный массив сложно читать не только МК, но и обычному
человеку. Поэтому я решил создать свою подбиблеотеку, в которой я как раз
и опишу весь массив. Создание и подключение оказалось довольно легким, но это
не изменило одного факта: массив трудно читаем, а так как он трудно читаем, то
и управлять всей матрицей тоже не просто. Обобщим: нам нужна такая программа,
в которой можно будет не только легко читать массив, но и управлять им.

\newpage
\subsection{Приложение}

Приложение -- самая сложная часть моего проекта т.к. на него было потрачено
немало усилий и времени. Поэтому я думаю, что вы будете не против посмотеть со
мной на части кода моего приложения.

Конечно буквы это хорошо, но не наглядно, поэтому надо создать наглядное
приложение, которым смогут все. Тут передо мной встал мучительный выбор:
создать приложение на питоне через tkinker, создать окружение canvas и
запрограммировать на JS или искать нечто новое. Так как я хотел, что-бы этот
был не только полезен для окружающих, я решил найти новые варианты решения.
В средней школе я немного изучал c++, так что изначально я рассчитывал на него,
но сделать что-либо дельное мне не удалось. В нем очень много ненужных для
меня возможностей, которые в конечном итоге заставили меня рассмотреть другие
варианты. И они нашлись. Целых 2 варианта было передо мной: processing.js и
processing.py. Первый имел собственную документацию, а второй был более легкий
для изучения, но я выбрал первый, т.к. я узнал о его особенности: он
встраиваемый: в его ядре заложен JavaScript поэтому его можно встроить
практически на любой сайт через canvas. Так я и пришел к выводу, что буду
делать код на processing.

Для начала хочу, что бы вы понимали, что я хотел от приложения, для этого
предлагаю вернуться на пару страниц назад. В пункте 8.5.2 говорится о кубе,
в котором большое количество маленьких кубиков. Первое о чем я подумал это
воссоздать такой куб в трехмерном пространстве, что-бы его можно было двигать
отключать/включать светодиоды(далее -- точки) и менять их цвета.

Получился не очень управляемый, но очень ресурсоёмкий серый куб. Следующий шаг
-- каждый кубик я изменил на сферу и получился большой куб из сфер.

\image{Куб из сфер.png}{200}{Куб из сфер}

Но это все еще был неуправляемый куб, которым запрогроммировать было ещё
сложнее, чем написать массив.
\newpage
После долгого перерыва на размышления я все-таки придумал первый рабочий
концепт приложения: справа сборка из слоев, слева текущий слой, в котором
можно изменить любую точку.

Я пошел писать это и вот, что получилось в итоге:

\image{Карта и сфера.png}{200}{Карта и сфера}

Но серая масса, которая изображает весь не включенный куб довольно мрачна.
Попробовав ее отключить я потерял вообще весь куб, так что я придумал так:
Серые, не включенные точки показываются только на текущем слое.

\image{Текущая сфера.png}{170}{Карта и текущая сфера}

Это уже был довольно большой успех, но впереди оставалась еще огромная работа.
Первым делом я сделал массива переключений точек. Теперь точки можно включать и
выключать.

\image{Включенная точка.png}{170}{Включенная точка}

\newpage
Но как изменить цвет? Я добавил еще по 3 массива для каждой точки. В каждом из
них хранятся значения от 0 до 255. Вы спросите зачем четыре массива, да еще и
переменные с типом \textcolor{blue}{int}. Дело в том, что я делал это все для
легкодоступности и потому что память позволяла. Теперь я мог поставить точку
не просто белого цвета, а случайного.

\image{Рандомная точка.png}{170}{Точки случайного цвета}

Но это еще не то, что нужно. Можно было бы сделать окошка ввода цвета, но тогда
для каждого цвета надо было бы лезть в интернет и копировать его hex, а я
добивался автономности. решил сделать свой colorpiker\footnote{colorpiker --
  программа предназначенная для выбора цвета}. За основу я взял фото всех цветов
радуги и и пользуясь фотошопом соединил его с бело-прозрачно-черным градиентом.

\image{hsv.jpg}{80}{Градиент}

Теперь, пользуясь возможностями языка вставляем фото вниз и описываем ф-цию,
которая сможет считывать с этого фото цвет и заносить его в цвет текущего
светодиода(в версии 1.3 -- в специальную глобальную переменную). Добавляем
этот цвет в виде квадрата внизу. Добавляем кнопку сохранить и очистить.

Теперь решим проблему переключения слоев. Первое, что приходит на ум -- сделать
кнопки вверх и вниз. Мне эта идея не понравилась т.к. на кнопки надо было бы
постоянно наводить курсор и нажимать -- не удобно. Другая идея пришла ко мне,
когда я уже начал искать в интернете как добавить на клавиши вверх и вниз
действия и, пролистывая страницу понял, что так же легко можно пролистывать и
слои. В этом случае processing не подвел и много кода писать не пришлось всего
несколько строк.

Оставалась одна проблема: куб был совершенно не подвижен, но добавив несколько
флагов на правую кнопку мыши я сделал так, что куб стало легко двигать из
любого места программы.

И так представляю вам версию 1.1

\image{v1.1.png}{250}{v1.1}

\subsubsection{функции setup и draw}

Перед тем как перейти к описанию самого кода я хочу сказать, что setup и draw
главные функции в языке processing. Аналогично ардуино функциям одна
выполняется на старте другая в цикле после выполнения первой

\newpage
\begin{flushright}\begin{huge}\textcolor{grey}{Processing}\end{huge}\end{flushright}
\begin{tabular}{c l}
  \hline
  \begin{lstlisting}[style=pmyLatexStyle]
int thisZ = 0;
int thisY = 0;
int thisX = 0;
int rotX = 20, prevRotX;
int rotY =20, prevRotY;
PImage img;
boolean clickFlag,
	turnFlag, leftClickFlag;
boolean[][][] dotArray = 
	new boolean[16][16][16];
int[][][] colR = new int [16][16][16];
int[][][] colG = new int [16][16][16];
int[][][] colB = new int [16][16][16];
int[][][] colA = new int [16][16][16];
PFont Font1;
void setup() {
	size(1920, 1027, P3D);
	textAlign(CENTER, CENTER);
	Font1 = createFont("Arial Bold", 18);
	textFont(Font1);
	fillArray();
	img = loadImage("hsv.jpg");
}
void draw() {  
	background(128, 128, 128);
	image(img, 0, 700);  
	circles();
	buttons();
	mouseTick();
	fill(255);
	textSize(25);
	text("Текущий цвет:", 95, 980);
	fill(colR[thisX][thisY][thisZ],
		colG[thisX][thisY][thisZ],
		colB[thisX][thisY][thisZ]);
	rect(200, 970, 50, 30);
	drawBalls();
}
\end{lstlisting}
   &
  \begin{tabular}{l}
    Описываем переменную слоя             \\
    Описываем переменные                  \\
    выбранной точки                       \\
    Описываем переменные                  \\
    смещения куба                         \\
    Описываем переменную изображения      \\
    Описываем переменные флагов           \\
    для положений мыши                    \\
    Описываем массив состояния            \\
    точки(вкл/выкл)                       \\
    Описываем массивы для каждого         \\
    цвета точки  по отдельности           \\
    и для установки яркости               \\
    (прозрачности точки))                 \\
    Описываем переменную шрифта           \\
    Начинаем функцию установки            \\
    Определяем размеры, пространство      \\
    Выравниваем весь текст по центру      \\
    Показываем какой шрифт                \\
    использовать (для поддержки русского) \\
    Заполняем массив           \\
    Загружаем фото в ОЗУ                  \\
    Заканчиваем установочную функцию      \\
    Начинаем постоянную функцию           \\
    Заливаем весь фон серым       \\
    Рисуем изображение                    \\
    Рисуем круги текущего слоя(см. 8.6.4)    \\
    Рисуем 2 кнопки(см. 8.6.2)               \\
    Перемещаемся по слоям         \\
    Заполняем буфер белым                 \\
    Устанавливаем размер цвета            \\
    Пишем надпись                         \\
    Заполняем буфер цветом точки          \\\\\\
    Рисуем прямоугольник                  \\
    Рисуем куб                            \\\\
  \end{tabular} \\
% \end{tabular}
\newpage

Думаю, что понимать этот язык гораздо легче, чем язык на ардуино, так что моих
комментариев должно хватать. Для дополнительных сведений можно обратиться на
сайт processing, ссылка на него будет в материалах.

\subsubsection{Кнопки и текст}

Думаю, что этот кусок кода я написал быстрее всего, т.к. processing облегчил
все до уровня приложения на одной функции и стандартные надписи в нем сделать
-- легче некуда.

\begin{flushright}\begin{huge}\textcolor{grey}{Processing}\end{huge}\end{flushright}
\begin{tabular}{c l}
  \hline
  \begin{lstlisting}[style=pmyLatexStyle]
void buttons() {
  stroke(0);
  fill(255);
  textSize(25);
  text("Cube generator", 250, 20);
  textSize(20);
  text("CLEAR", 25+100/2, 640);
  text("SAVE", 135+100/2, 640);
  fill(255, 0, 0);
  text("Z:", 75, 50);
  text(thisZ, 94, 50);
  text("X:", 125, 50);
  text(thisX, 144, 50);
  text("Y:", 175, 50);
  text(thisY, 194, 50);
}
\end{lstlisting}
   &
  \begin{tabular}{l}
    Начинаем ф-цию кнопок        \\
    Рисуем окантовку             \\
    Устанавливаем размер текста  \\
    Пишем название               \\
    Заливаем буфер белым         \\
    Уменьшаем текст              \\
    Добавляем кнопку "Очистить"  \\
    Добавляем кнопку "Сохранить" \\
    Заливаем буфер красным       \\
    Пишем позицию слоя Z         \\\\
    Пишем позицию точки X        \\\\
    Пишем позицию точки Y        \\\\
    Заканчиваем ф-цию            \\
  \end{tabular} \\
\end{tabular}

Позиции я выводил для тестирования, но затем они настолько мне понравились,
что я их оставил и ориентировался иногда по ним (особенно по слоям). Стоит
сказать что окантовка -- 2 пикселя рядом с фигурой, которую мы планируем
нарисовать. Она как и все элементы заливается цветом из буфера.

Так как мы поговорили о кнопках, то предлагаю разобраться, что скрывается
внутри них.

\newpage
\subsubsection{Кнопка очистить}

По сути она стирает все массивы и заполняет их нулями.

\begin{flushright}\begin{huge}\textcolor{grey}{Processing}\end{huge}\end{flushright}
\begin{tabular}{c l}
  \hline
  \begin{lstlisting}[style=pmyLatexStyle]
void clearCube() {
  for (byte k = 0; k < 16; k++)
    for (byte i = 0; i < 16; i++)
      for (byte j = 0; j < 16; j++) {        
        dotArray[i][j][k] = false;
        colR[i][j][k]=0;
        colG[i][j][k]=0;
        colB[i][j][k]=0;
      }
}
\end{lstlisting}
   &
  \begin{tabular}{l}
    Начинаем ф-цию очистки     \\
    Определяем циклы по 3 осям \\\\\\
    Выключаем каждую точку     \\
    Задаем для каждой          \\точки черный цвет\\\\\\\\
  \end{tabular} \\
\end{tabular}

\subsubsection{Функция кругов}

Функция кругов -- важная функция, она отвечает за рисовку кругов текущего
слоя слева. Но она не отвечает за выбор включен ли круг или выключен и какого
цвета он. За это отвечает другая функция о которой речь пойдет позже.

\begin{flushright}\begin{huge}\textcolor{grey}{Processing}\end{huge}\end{flushright}
\begin{tabular}{c l}
  \hline
  \begin{lstlisting}[style=pmyLatexStyle]
void circles() {
  stroke(255);
  for (byte x = 0; x < 16; x++) {
    for (byte y = 0; y < 16; y++) {
      if (dotArray[x][y][thisZ]) {
        fill(colR[x][y][thisZ],
					colG[x][y][thisZ],
					colB[x][y][thisZ]);
        if (colR[x][y][thisZ]==0) {
          if (colB[x][y][thisZ]==0) {
            if (colG[x][y][thisZ]==0) {
              colR[x][y][thisZ]=255;
              colG[x][y][thisZ]=255;
              colB[x][y][thisZ]=255;}}}
      } else { 
        fill(0);
      }
      circle(x*25+50, y*25+90, 20);}}}
\end{lstlisting}
   &
  \begin{tabular}{l}
    Начинаем ф-цию кругов    \\
    Заливаем окантовку       \\
    Определяем цикл по оси X \\
    Определяем цикл по оси Y \\
    Если точка включена      \\
    Забираем ее цвет и       \\ заливаем в буфер\\\\
    Если её цвет - черный    \\\\\\
    то делаем его белым      \\\\\\
    Если она отключена       \\
    делаем его черным        \\\\
    Рисуем саму точку
  \end{tabular} \\
\end{tabular}

\subsubsection{Фунцкия сохранения}
Функция создает строку в который записан массив для Arduino.
\begin{flushright}\begin{huge}\textcolor{grey}{Processing}\end{huge}\end{flushright}
\begin{tabular}{c l}
  \hline
  \begin{lstlisting}[style=pmyLatexStyle]
void saveBitmap() {
  String[] lines = new String[18];
  text("SAVED", 100, 10);
  lines[0] =
'const uint32_t arot[16][256] PROGMEM={';
  for (int z = 0; z < 16; z++) {    
    lines[z+1] = "\t{";    
    for (byte y = 0; y < 16; y++) {  
      for (byte x = 0; x < 16; x++) {
        if (x*y!=225){
        if (dotArray[x][y][z]){
        String hex = String.format(
			"0x%02x%02x%02x",
			colR[x][y][z],
			colG[x][y][z],
			colB[x][y][z]);  
        print(hex);
        lines[z+1] += hex+",";}
        else {
        lines[z+1] += "0x000000"+",";
      }}else{
        if (dotArray[x][y][z]){
        String hex = String.format(
			"0x%02x%02x%02x",
			colR[x][y][z],
			colG[x][y][z],
			colB[x][y][z]);  
        lines[z+1] +=hex;}
        else 
			{ lines[z+1] += "0x000000";}}}}
    lines[z+1] += "},";}
  lines[17] = "};";
  saveStrings(
	  "../Gologramm_3dpov/lines.ino", 
	  lines);}
\end{lstlisting}
   &
  \begin{tabular}{l}
    Начинаем функцию сохранения     \\
    Создаем строку lines            \\
    Пишем "сохранено"               \\
    Задаем начальную                \\
    строку(см. 8.5.2)               \\
    Задаем цикл слоев               \\
    Добавляем массив                \\
    Задаем цикл по точкам           \\
    \\
    Проверяем конец                 \\
    Если точка включена             \\
    Создаем hex из RGB              \\
    \\
    \\
    \\
    \\
    Выводим созданный цвет          \\
    Добавляем цвет в строку         \\
    Если точка выключена            \\
    Добавляем черный в строку       \\
    Если это последнее значение     \\
    Проделываем все то же,          \\
    но без запятой на конце         \\
    \\
    \\
    \\
    \\
    \\
    \\
    \\
    В конец слоя добавляем \};      \\
    В конце строки закрываем массив \\
    Сохраняем в папку с кодом       \\ для ардуино
    \\\\
  \end{tabular} \\
\end{tabular}

\newpage
\subsubsection{Функция нажатия кнопки мыши}

Если мы уже разобрали функции сохранения и очистки и настало время разобрать
код для кнопок. Первое, что я хочу отметить это то, что функций кнопок вообще
нету в processing Просто при наведении в квадрат мышью выполняемся та или иная
функция. В начале мы описываем бул-функцию которая возвращает внутри круга была
нажата мышь или нет.

\begin{flushright}\begin{huge}\textcolor{grey}{Processing}\end{huge}\end{flushright}
\begin{tabular}{c l}
  \hline
  \begin{lstlisting}[style=pmyLatexStyle]
boolean overCircle(int x, 
  int y, int diameter) {
  float disX = 
    x - mouseX;
  float disY = 
    y - mouseY;
  if (sqrt(sq(disX) + 
    sq(disY)) < diameter/2 ) {
    return true;} 
  else {return false;}}
void mouseTick() {
  if (mousePressed && 
    (mouseButton == RIGHT)) {
    clickFlag = true;
    turnFlag = true;
  }
  if (mousePressed && 
    (mouseButton == LEFT)) {
    if (!leftClickFlag) {
      leftClickFlag = true;
      if (overRect(25, 600,
        100, 40)) clearCube();
      if (overRect(135, 600,
        100, 40)) saveBitmap();
      for (byte x = 0; x < 16; x++) {
        for (byte y = 0; y < 16; y++) {
          if (overCircle(x*25+50,
            y*25+90, 20)) {
            dotArray[x][y][thisZ] = 
              !dotArray[x][y][thisZ];
            thisX=x;
            thisY=y;}}}}}
\end{lstlisting}
   &
  \begin{tabular}{l}
    Начинаем бул-функцию     \\
    \\
    Вычисляем дистанцию      \\
    по осям                  \\
    \\
    \\
    Если дистанция попадает  \\
    В круги то возвращаем    \\
    Истина                   \\
    Иначе Ложь               \\
    Начинаем ф-цию мыши      \\
    Если кнопка нажата       \\
    И она правая             \\
    То Включаем все флаги    \\
    \\
    \\
    Если кнопка нажата       \\
    И она левая              \\
    Если ее флаг выкл.       \\
    То включаем его          \\
    Если она была нажата     \\
    На кнопке Clear очистить \\
    Если на кнопке Save      \\
    То Сохраняем             \\
    Задаем циклы по осям     \\
    \\
    Если мышь в круге        \\
    \\
    То инвертируем значение  \\
    Массива точек            \\
    Задаем значения текущих  \\
    Осей                     \\
  \end{tabular} \\
\end{tabular}

\subsubsection{Функция колесика}

Как я уже говорил ранее колесико мыши будет служить для переключения слоев.
Описал я её так:

\begin{flushright}\begin{huge}\textcolor{grey}{Processing}\end{huge}\end{flushright}
\begin{tabular}{c l}
  \hline
  \begin{lstlisting}[style=pmyLatexStyle]
void mouseWheel(MouseEvent event) {
  float e = event.getCount();
  thisZ -= e;
  if (thisZ < 0) thisZ = 0;
  if (thisZ > 15) thisZ = 15;}
\end{lstlisting}
   &
  \begin{tabular}{l}
    Начинаем ф-цию колесика                  \\
    Забираем значение прокрученных единиц    \\
    Вычитаем эти единицы из слоев            \\
    Если слой отрицательный, то слой нулевой \\
    Если слой больше 15, то слой 15-й        \\
  \end{tabular} \\
\end{tabular}

\subsubsection{Функция рисования куба}

Последняя функция в версии 1.1 это функция рисования куба. Куб я делал дольше
всего т.к. он трехмерный , да еще и должен быть полупрозрачным.\\
%\begin{flushright}\begin{huge}\textcolor{grey}{Processing}\end{huge}\end{flushright}
\begin{tabular}{c l}
  \hline
  \begin{lstlisting}[style=pmyLatexStyle]
void drawBalls() {
  noStroke();
  fill(255);
  lights();
  translate(1280/2+150,
    360, -25*4);
  rotateY(rotX * 0.017);
  rotateX(rotY * 0.017);
  translate(-25*4+25/2, 
    -25*4+25/2, 25*4);
  for (byte z = 0; z < 16; z++) {
    for (byte y = 0; y < 16; y++) {
      for (byte x = 0; x < 16; x++) {
        if (dotArray[x][y][z] 
          == true) {
          fill(colR[x][y][z], 
            colG[x][y][z], colB[x][y][z]);
          sphere(10);
        } else {
          fill(colR[x][y][z], colG[x][y][z], 
            colB[x][y][z], 30);
          if (z == thisZ) sphere(10);}
        translate(25, 0, 0);}
      translate(-25*16, 25, 0);}
    translate(0, -25*16, -25);}}
\end{lstlisting}
   &
  \begin{tabular}{l}
    Начинаем ф-цию сфер                \\
    Без выделения                      \\
    Заливаем буфер белым               \\
    Добавляем искусственный цвет       \\
    Задаем позицию                     \\
    \\
    И смещение                         \\
    \\
    Смещаем позицию                    \\
    \\
    Задаем цикл слоев                  \\
    Задаем циклы осей                  \\
    \\
    Если точка включена, то            \\
    \\
    Заливаем буфер её цветом           \\\\
    И рисуем сферу                     \\
    Если выключена                     \\
    Заливаем цветом с                  \\
    пониженой прозрачностью            \\
    Если текущий слой, то рисуем сферу \\
    Трансформируем по X                \\
    Трансформируем по Y                \\
    Трансформируем по Z                \\
  \end{tabular} \\
\end{tabular}
\newpage

\subsubsection{Другие версии}

До защиты проекта я успел немного усовершенствовать свое приложение для его
удобства и совместимости.\\
\textbf{Версия 1.2}

В этой версии удалены проблемы с совместимостью языка со старыми nvidia
видеокартами, куб смещен вниз для более удобного просмотра\\
\textbf{Версия 1.3}

Удалено автозаполнение, исправлены проблемы с цветом. Ранее каждая точка
заливалась белым, теперь она заливается текущим цветом.\\
\textbf{Версия 1.4}

Добавлена автозагрузка из приложения непосредственно в arduino.
\subsubsection{Дополнительные примеры работы приложения}

\image{Куб в приложении.png}{180}{Куб}
\image{Октаэдр.png}{180}{Октаэдр}

\newpage

\subsection{Дополнения}

\subsubsection{\LaTeX}

\LaTeX -- это язык программирования, созданный математиком Дональдом Кнутом для
печати книг или журналов. Я его использовал для написания реферата, т.к. в этом
формате мне гораздо легче напечатать текст, чем в Word или OpenDocument
формате. Так же на него распространяются все расширения, установленные в моей
среде разработки Virtual Studio Code так что проверка грамотности и удобное
выделение напечатанного тоже было доступно. В общей сумме весь реферат занял
$\pm$2000 строк кода в \LaTeX и размер \TeX-файла превысил 150Кб. Для
наглядности покажу, как выглядит этот абзац до форматирования в pdf и еще
несколько примеров.

\image{Абзац.png}{100}{Предыдущий абзац}
\image{Таблица.png}{250}{Таблица типов}
\newpage

\subsubsection{Повтор проекта}

Я довольно подробно описал в этом реферате как и что я сделал и почему.
Последние версии моего проекта я выкладывал на github и один мальчик, увидев мой
проект скопировал мой код и полностью повторил проект. Вот что у него
получилось:

\image{его.jpg}{540}{Голограмма, созданная по моему реферату}
\newpage
\subsubsection{Цена}

Последнее, что я хотел бы сказать о своем продукте это таблицу цен и во сколько
мой проект мне обошелся.

\begin{center}
  \begin{tabular}{|c|c|c|c|c|}
    \hline
    Название             & Количество & Цена         & Цена при      & Общая       \\
                         &            & сейчас(\rub) & покупке(\rub) & сумма(\rub) \\
    \hline
    Матрица 16$\times$16 & 1          & 1000         & 1000          & 1000        \\
    \hline
    Лист фанеры          & 1          & 600          & 230           & 230         \\
    \hline
    Ethernet-кабель      & 1          & 200          & --            & 0           \\
    \hline
    Arduino Nano         & 1          & 300          & 120           & 120         \\
    \hline
    Реле                 & 1          & 150          & 120           & 120         \\
    \hline
    Аккумулятор          & 1          & 100          & 100           & 100         \\
    \hline
    Оптический датчик    & 1          & 120          & 100           & 100         \\
    \hline
    Орк-стекло           & 2          & 400          & --            & 0           \\
    \hline
    Мотор                & 1          & 100          & 100           & 100         \\
    \hline
    Металлический прут   & 1          & 60           & 60            & 60          \\
    \hline
    Алюминиевый лист     & 1          & 40           & 40            & 40          \\
    \hline
  \end{tabular}
\end{center}
В итоге весь проект мне обошелся в 1870\rub. По моим меркам, если данную поделку будут продавать в магазинах, то она будет стоить гораздо дороже.
\newpage
\section{Области применения и планы на следующие версии}

Мой проект изначально создавался в качестве простой инновации, потому
что так еще никто не делал, но все-таки ему нужна одна или несколько
областей применения. Они нашлись довольно быстро под конец создания
продукта, кода уже было понятно что где будет и как все будет
выглядеть в конце.

\begin{enumerate}
  \item Сфера обучения (наглядное пособие поведения того или иного
        материала, частицы или точки для более подробного изучения
        предмета)
  \item Сфера it (наглядное заполнение bool тензоров)
  \item Сфера машиностроения (Светофоры без перегородок сможет
        увидеть каждый автомобилист, даже на встречной дороге)
\end{enumerate}

Хочу заметить, что это не последняя версия проекта
и я хочу посвятить некоторое время летних каникул для того, что бы
сделать несколько правок для улучшения работоспособности механизма.

\begin{enumerate}
  \item Добавить модуль памяти для вывода динамических изображений
  \item Оптимизировать собственную библиотеку отказавшись от
        использования Adafruit NeoPixel.
  \item Исправить проблемы с приложением, выгрузить его в интернет
  \item Создать собственный сайт с возможностью дистанционного
        управления голограммой
\end{enumerate}
Все материалы, относящиеся к проекту можно найти на сайте
\href{https://github.com/pluttan/Persistence_of_vision} или по
QR-коду:
\image{qr-code.png}{200}{QR код}
\newpage
\ttfamily
\section{Список использованной литературы}
\subsection{Интернет-документы:}
\begin{enumerate}
  \item Интернет-ресурс, новостной канал. \\
        Режим доступа(URL):\href{https://masterok.livejournal.com/s/4469932.html} \\
        (дата обращения: 12.12.2020).
  \item Интернет-ресурс, свободная энциклопедия. \\
        Режим доступа(URL): \href{https://dic.academic.ru/dic.nsf/ruwiki/1506240}\\
        (дата обращения: 12.12.2020).
  \item Интернет-ресурс, физическое объяснение зрения. \\
        Режим доступа(URL):\href{https://zreni.ru/articles/tehnicheskoe-zrenie/2194-inerciya-zreniya.html} \\
        (дата обращения: 12.12.2020).
  \item Интернет-ресурс, личный блог. \\
        Режим доступа(URL): \href{https://alexgyver.ru/3dpov} \\
        (дата обращения: 12.12.2020).
  \item Интернет-ресурс, документация\\
        Режим доступа(URL): \href{https://processing.org/}\\
        (дата обращения:29.03.2021)
\end{enumerate}
\subsection{Монографии(книги):}
\begin{enumerate}
  \item М. Д. Артамонов, М. М. Морин, Г. А. Скворцов// ОСНОВЫ ТЕОРИИ И КОНСТРУИРОВАНИЯ АВТОТРАКТОРНЫХ ДВИГАТЕЛЕЙ 1978г. -- стр.3-11,123 \item С.М. Львовский//LaTeX: Подробное содержание 1986г.
\end{enumerate}
\end{document}

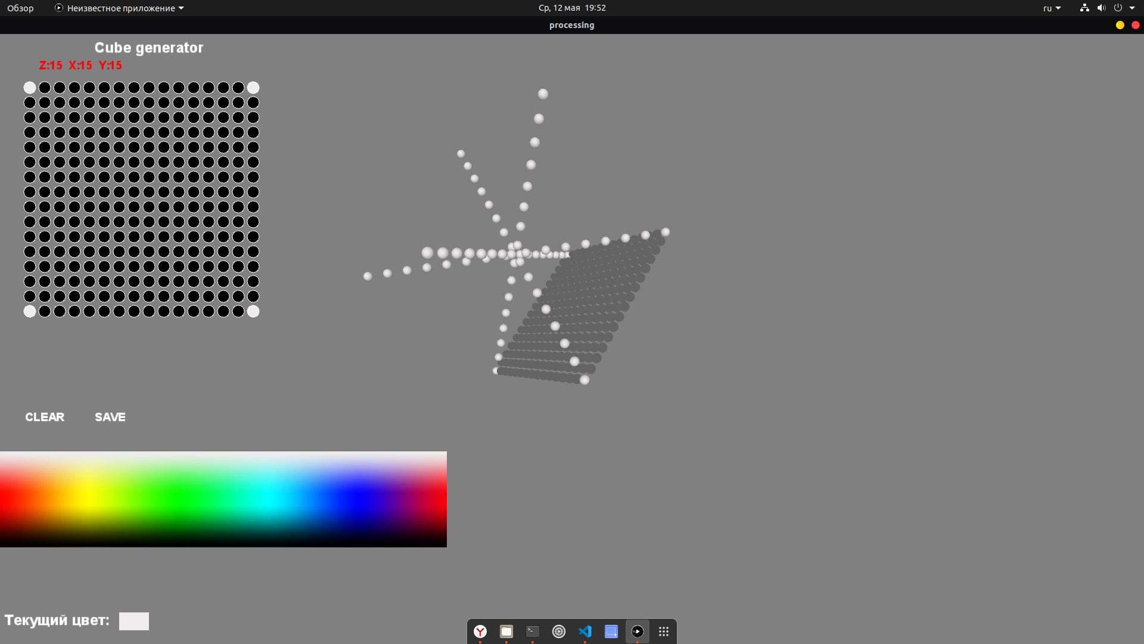
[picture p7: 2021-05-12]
Реферат/conf/img/v1.1.png

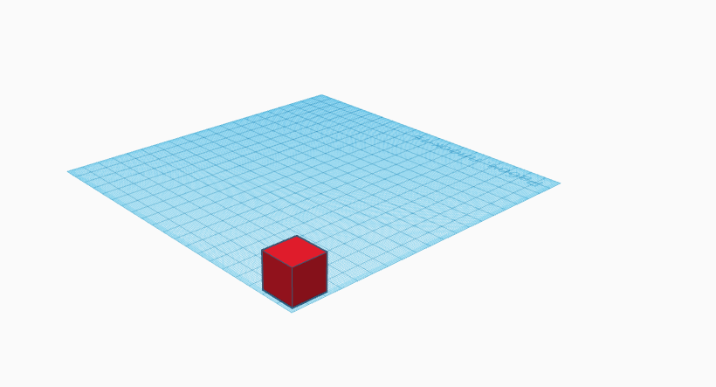
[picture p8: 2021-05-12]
Реферат/conf/img/Куб.png

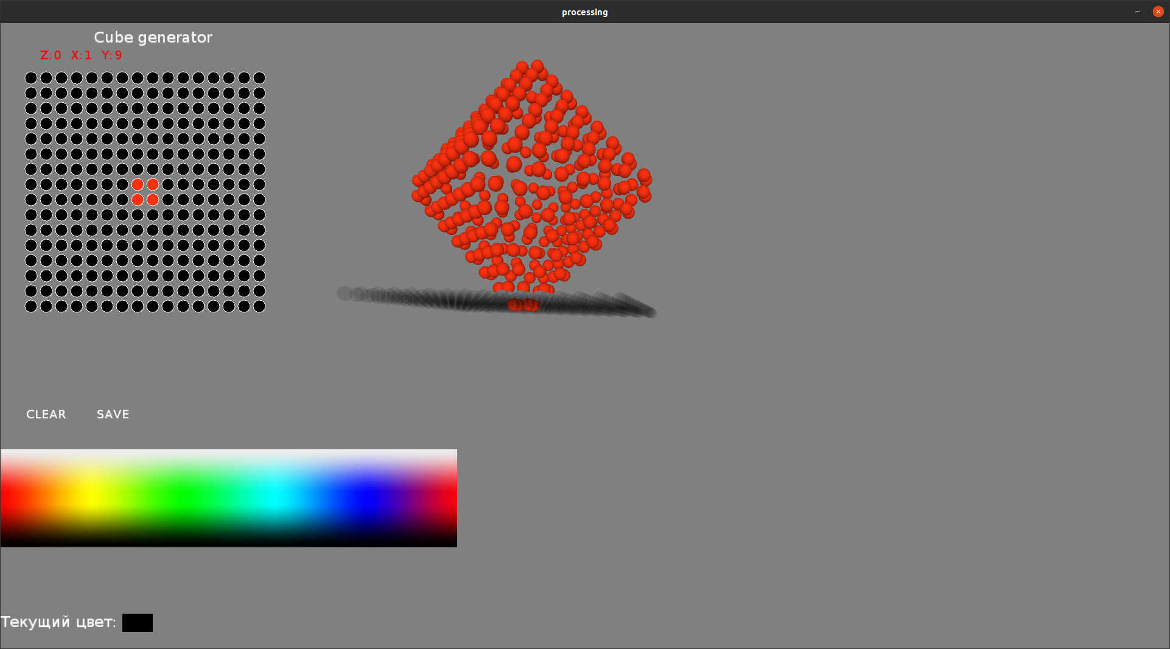
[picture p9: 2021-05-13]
Реферат/conf/img/Октаэдр.png

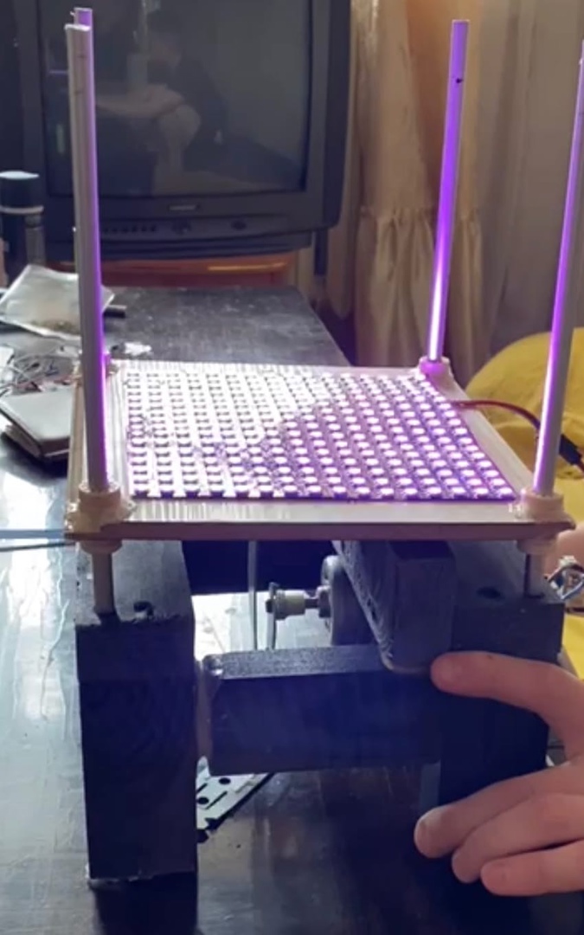
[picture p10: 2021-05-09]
Реферат/conf/img/его.jpg

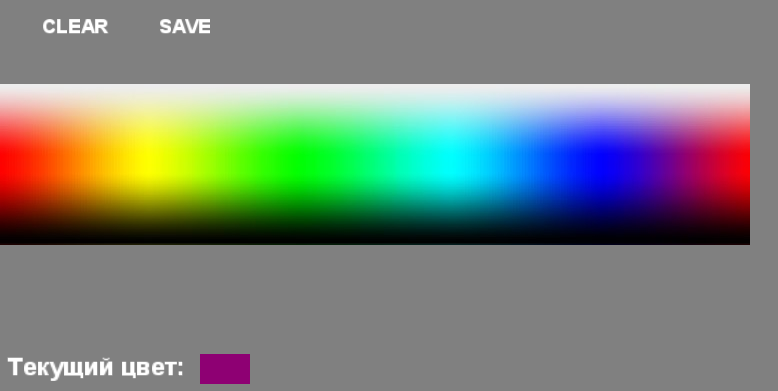
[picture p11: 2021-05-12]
Реферат/conf/img/colorpiker.png

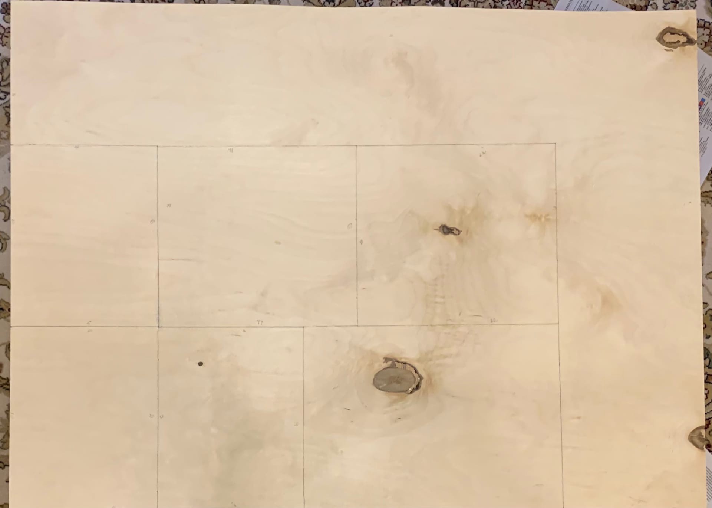
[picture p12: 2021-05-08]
Реферат/conf/img/разметка фанеры.jpg

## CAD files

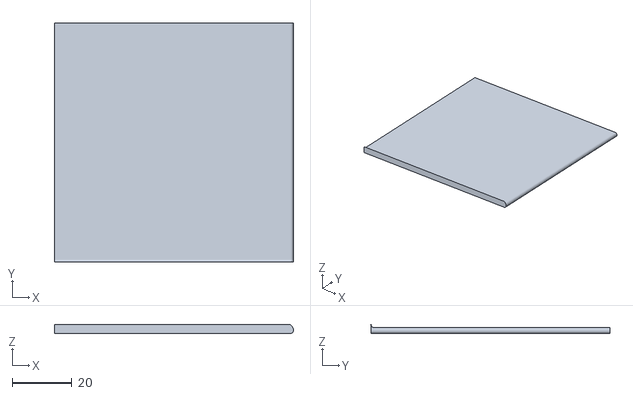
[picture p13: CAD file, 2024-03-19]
3д печать/платформа/тело5.obj
80.0 x 80.0 x 3.00

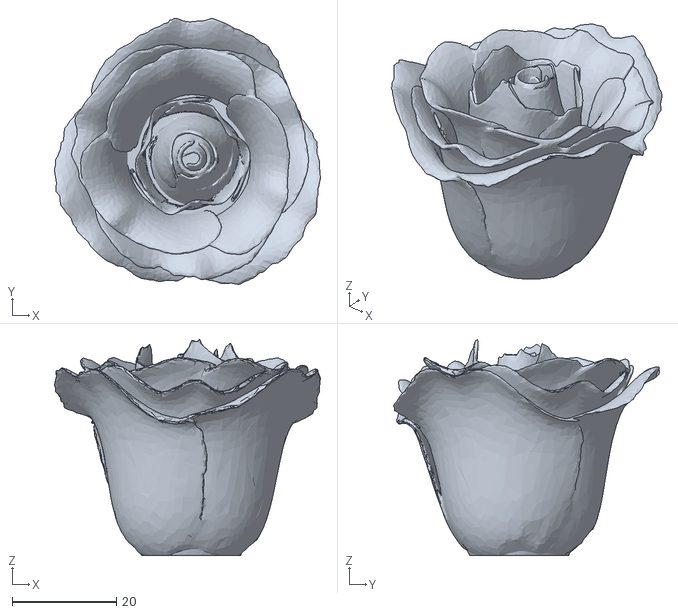
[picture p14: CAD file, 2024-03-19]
stl cutter/rosa_led.stl
51.0 x 51.0 x 41.5

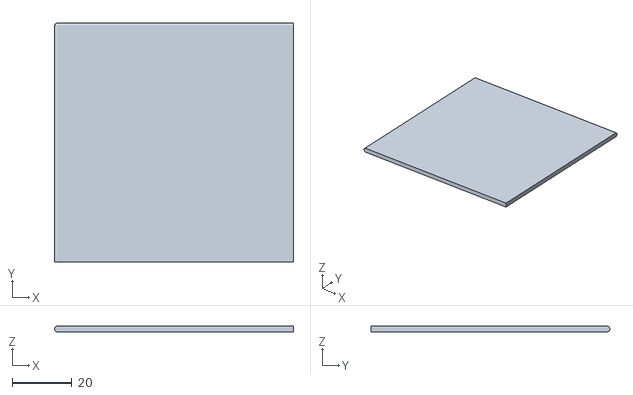
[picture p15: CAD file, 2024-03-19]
3д печать/платформа/тело1.obj
80.0 x 80.0 x 2.00

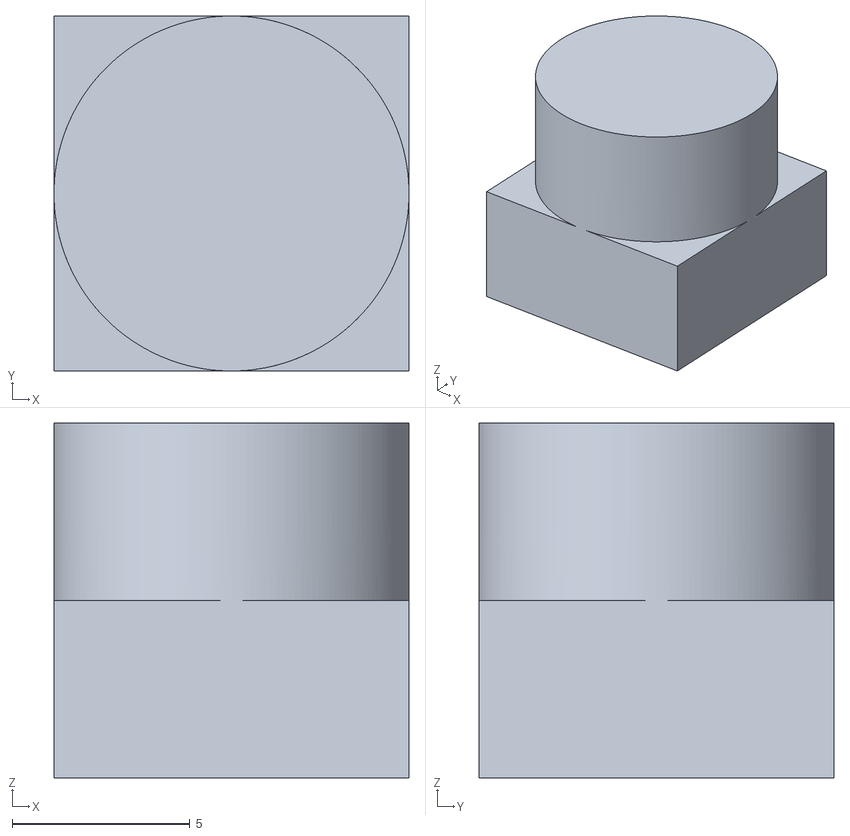
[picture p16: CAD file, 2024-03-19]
stl cutter/Body1.stl
10.0 x 10.0 x 10.0

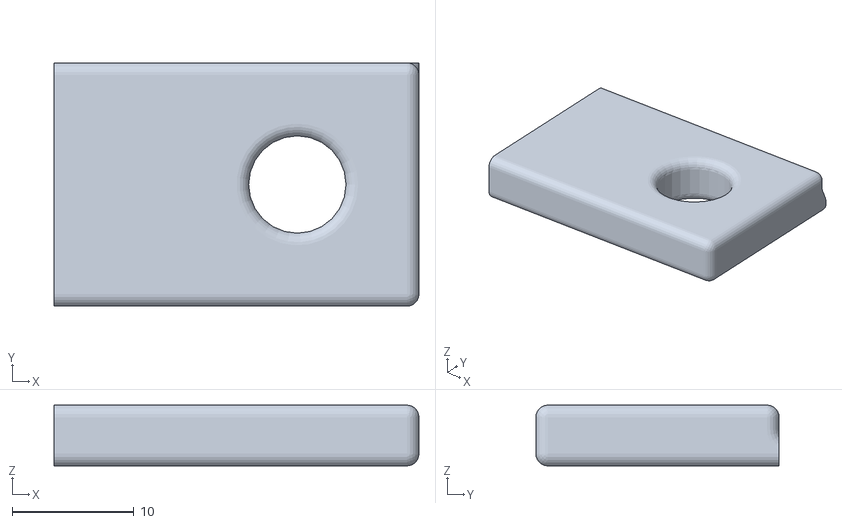
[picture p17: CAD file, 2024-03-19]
3д печать/платформа/тело7.obj
30.0 x 20.0 x 5.00

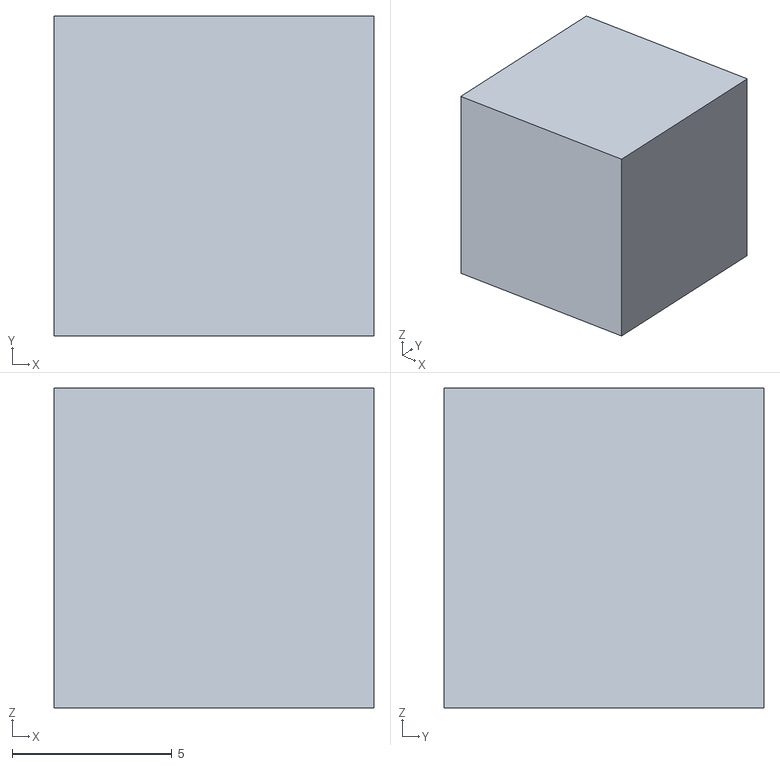
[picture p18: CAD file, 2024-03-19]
stl cutter/Body2.stl
10.0 x 10.0 x 10.0

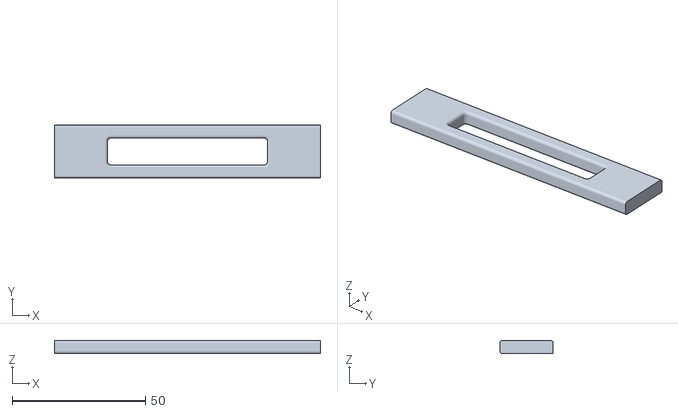
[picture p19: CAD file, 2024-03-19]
3д печать/платформа/тело6.obj
100.0 x 20.0 x 5.00

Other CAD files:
3д печать/платформа/тело4.obj
3д печать/платформа/тело3.obj
3д печать/платформа/тело2.obj

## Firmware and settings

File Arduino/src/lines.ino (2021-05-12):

const uint32_t arot[16][256] PROGMEM = {
	{0x000000,0x000000,0x000000,0xffffff,0x000000,0xffffff,0xffffff,0xffffff,0x000000,0xffffff,0xffffff,0x000000,0x000000,0x000000,0x000000,0x000000,0xffffff,0x000000,0xffffff,0x000000,0x000000,0x000000,0x000000,0xffffff,0x000000,0x000000,0x000000,0xffffff,0x000000,0x000000,0x000000,0x000000,0x000000,0xffffff,0xffffff,0x000000,0xffffff,0x000000,0xffffff,0xffffff,0x000000,0xffffff,0xffffff,0xffffff,0x000000,0x000000,0x000000,0xffffff,0x000000,0x000000,0xffffff,0x000000,0xffffff,0x000000,0x000000,0xffffff,0xffffff,0x000000,0x000000,0x000000,0x000000,0x000000,0xffffff,0x000000,0x000000,0x000000,0xffffff,0xffffff,0xffffff,0x000000,0x000000,0x000000,0x000000,0xffffff,0x000000,0xffffff,0xffffff,0xffffff,0x000000,0x000000,0x000000,0x000000,0xffffff,0xffffff,0x000000,0x000000,0xffffff,0xffffff,0xffffff,0x000000,0x000000,0xffffff,0xffffff,0xffffff,0x000000,0x000000,0xffffff,0xffffff,0xffffff,0xffffff,0x000000,0x000000,0x000000,0x000000,0x000000,0x000000,0xffffff,0x000000,0xffffff,0x000000,0x000000,0x000000,0xffffff,0xffffff,0xffffff,0x000000,0x000000,0xffffff,0xffffff,0xffffff,0xffffff,0xffffff,0xffffff,0x000000,0x000000,0x000000,0x000000,0x000000,0x000000,0xffffff,0xffffff,0x000000,0xffffff,0x000000,0x000000,0x000000,0xffffff,0x000000,0x000000,0x000000,0xffffff,0xffffff,0xffffff,0xffffff,0x000000,0x000000,0xffffff,0x000000,0x000000,0xffffff,0xffffff,0x000000,0xffffff,0x000000,0x000000,0xffffff,0xffffff,0xffffff,0xffffff,0x000000,0x000000,0x000000,0x000000,0xffffff,0xffffff,0xffffff,0xffffff,0xffffff,0x000000,0xffffff,0xffffff,0x000000,0xffffff,0xffffff,0x000000,0x000000,0x000000,0xffffff,0xffffff,0xffffff,0x000000,0xffffff,0x000000,0x000000,0x000000,0xffffff,0xffffff,0x000000,0x000000,0x000000,0x000000,0xffffff,0xffffff,0x000000,0x000000,0xffffff,0xffffff,0xffffff,0x000000,0xffffff,0x000000,0x000000,0x000000,0x000000,0xffffff,0x000000,0x000000,0x000000,0xffffff,0x000000,0x000000,0x000000,0xffffff,0x000000,0xffffff,0xffffff,0x000000,0xffffff,0x000000,0x000000,0x000000,0x000000,0xffffff,0xffffff,0xffffff,0xffffff,0xffffff,0xffffff,0x000000,0xffffff,0xffffff,0xffffff,0x000000,0xffffff,0x000000,0x000000,0xffffff,0xffffff,0x000000,0xffffff,0xffffff,0xffffff,0x000000,0xffffff,0xffffff,0xffffff,0xffffff,0xffffff,0xffffff,0x000000,0x000000,0xffffff,0x000000,0xffffff,0xffffff,0x000000},
	{0x000000,0x000000,0x000000,0x000000,0x000000,0x000000,0x000000,0x000000,0x000000,0x000000,0x000000,0x000000,0x000000,0x000000,0x000000,0x000000,0x000000,0x000000,0x000000,0x000000,0x000000,0x000000,0x000000,0x000000,0x000000,0x000000,0x000000,0x000000,0x000000,0x000000,0x000000,0x000000,0x000000,0x000000,0x000000,0x000000,0x000000,0x000000,0x000000,0x000000,0x000000,0x000000,0x000000,0x000000,0x000000,0x000000,0x000000,0x000000,0x000000,0x000000,0x000000,0x000000,0x000000,0x000000,0x000000,0x000000,0x000000,0x000000,0x000000,0x000000,0x000000,0x000000,0x000000,0x000000,0x000000,0x000000,0x000000,0x000000,0x000000,0x000000,0x000000,0x000000,0x000000,0x000000,0x000000,0x000000,0x000000,0x000000,0x000000,0x000000,0x000000,0x000000,0x000000,0x000000,0x000000,0x000000,0x000000,0x000000,0x000000,0x000000,0x000000,0x000000,0x000000,0x000000,0x000000,0x000000,0x000000,0x000000,0x000000,0x000000,0x000000,0x000000,0x000000,0x000000,0x000000,0x000000,0x000000,0x000000,0x000000,0x000000,0x000000,0x000000,0x000000,0x000000,0x000000,0x000000,0x000000,0x000000,0x000000,0x000000,0x000000,0x000000,0x000000,0x000000,0x000000,0x000000,0x000000,0x000000,0x000000,0x000000,0x000000,0x000000,0x000000,0x000000,0x000000,0x000000,0x000000,0x000000,0x000000,0x000000,0x000000,0x000000,0x000000,0x000000,0x000000,0x000000,0x000000,0x000000,0x000000,0x000000,0x000000,0x000000,0x000000,0x000000,0x000000,0x000000,0x000000,0x000000,0x000000,0x000000,0x000000,0x000000,0x000000,0x000000,0x000000,0x000000,0x000000,0x000000,0x000000,0x000000,0x000000,0x000000,0x000000,0x000000,0x000000,0x000000,0x000000,0x000000,0x000000,0x000000,0x000000,0x000000,0x000000,0x000000,0x000000,0x000000,0x000000,0x000000,0x000000,0x000000,0x000000,0x000000,0x000000,0x000000,0x000000,0x000000,0x000000,0x000000,0x000000,0x000000,0x000000,0x000000,0x000000,0x000000,0x000000,0x000000,0x000000,0x000000,0x000000,0x000000,0x000000,0x000000,0x000000,0x000000,0x000000,0x000000,0x000000,0x000000,0x000000,0x000000,0x000000,0x000000,0x000000,0x000000,0x000000,0x000000,0x000000,0x000000,0x000000,0x000000,0x000000,0x000000,0x000000,0x000000,0x000000,0x000000,0x000000,0x000000,0x000000,0x000000,0x000000,0x000000,0x000000,0x000000,0x000000,0x000000,0x000000,0x000000,0x000000,0x000000,0x000000,0x000000,0x000000,0x000000,0x000000,0x000000},
	{0x000000,0x000000,0x000000,0x000000,0x000000,0x000000,0x000000,0x000000,0x000000,0x000000,0x000000,0x000000,0x000000,0x000000,0x000000,0x000000,0x000000,0x000000,0x000000,0x000000,0x000000,0x000000,0x000000,0x000000,0x000000,0x000000,0x000000,0x000000,0x000000,0x000000,0x000000,0x000000,0x000000,0x000000,0x000000,0x000000,0x000000,0x000000,0x000000,0x000000,0x000000,0x000000,0x000000,0x000000,0x000000,0x000000,0x000000,0x000000,0x000000,0x000000,0x000000,0x000000,0x000000,0x000000,0x000000,0x000000,0x000000,0x000000,0x000000,0x000000,0x000000,0x000000,0x000000,0x000000,0x000000,0x000000,0x000000,0x000000,0x000000,0x000000,0x000000,0x000000,0x000000,0x000000,0x000000,0x000000,0x000000,0x000000,0x000000,0x000000,0x000000,0x000000,0x000000,0x000000,0x000000,0x000000,0x000000,0x000000,0x000000,0x000000,0x000000,0x000000,0x000000,0x000000,0x000000,0x000000,0x000000,0x000000,0x000000,0x000000,0x000000,0x000000,0x000000,0x000000,0x000000,0x000000,0x000000,0x000000,0x000000,0x000000,0x000000,0x000000,0x000000,0x000000,0x000000,0x000000,0x000000,0x000000,0x000000,0x000000,0x000000,0x000000,0x000000,0x000000,0x000000,0x000000,0x000000,0x000000,0x000000,0x000000,0x000000,0x000000,0x000000,0x000000,0x000000,0x000000,0x000000,0x000000,0x000000,0x000000,0x000000,0x000000,0x000000,0x000000,0x000000,0x000000,0x000000,0x000000,0x000000,0x000000,0x000000,0x000000,0x000000,0x000000,0x000000,0x000000,0x000000,0x000000,0x000000,0x000000,0x000000,0x000000,0x000000,0x000000,0x000000,0x000000,0x000000,0x000000,0x000000,0x000000,0x000000,0x000000,0x000000,0x000000,0x000000,0x000000,0x000000,0x000000,0x000000,0x000000,0x000000,0x000000,0x000000,0x000000,0x000000,0x000000,0x000000,0x000000,0x000000,0x000000,0x000000,0x000000,0x000000,0x000000,0x000000,0x000000,0x000000,0x000000,0x000000,0x000000,0x000000,0x000000,0x000000,0x000000,0x000000,0x000000,0x000000,0x000000,0x000000,0x000000,0x000000,0x000000,0x000000,0x000000,0x000000,0x000000,0x000000,0x000000,0x000000,0x000000,0x000000,0x000000,0x000000,0x000000,0x000000,0x000000,0x000000,0x000000,0x000000,0x000000,0x000000,0x000000,0x000000,0x000000,0x000000,0x000000,0x000000,0x000000,0x000000,0x000000,0x000000,0x000000,0x000000,0x000000,0x000000,0x000000,0x000000,0x000000,0x000000,0x000000,0x000000,0x000000,0x000000,0x000000,0x000000,0x000000},
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

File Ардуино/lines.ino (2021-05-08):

const uint32_t arot[16][256] PROGMEM = {
	{0x07f3fe,0x07f3fe,0x07f3fe,0x07f3fe,0x07f3fe,0x07f3fe,0x07f3fe,0x07f3fe,0x07f3fe,0x07f3fe,0x07f3fe,0x07f3fe,0x07f3fe,0x07f3fe,0x07f3fe,0x07f3fe,0x07f3fe,0x000000,0x000000,0x000000,0x000000,0x000000,0x000000,0x000000,0x000000,0x000000,0x000000,0x000000,0x000000,0x000000,0x000000,0x07f3fe,0x07f3fe,0x000000,0x000000,0x000000,0x000000,0x000000,0x000000,0x000000,0x000000,0x000000,0x000000,0x000000,0x000000,0x000000,0x000000,0x07f3fe,0x07f3fe,0x000000,0x000000,0x000000,0x000000,0x000000,0x000000,0x000000,0x000000,0x000000,0x000000,0x000000,0x000000,0x000000,0x000000,0x07f3fe,0x07f3fe,0x000000,0x000000,0x000000,0x000000,0x000000,0x000000,0x000000,0x000000,0x000000,0x000000,0x000000,0x000000,0x000000,0x000000,0x07f3fe,0x07f3fe,0x000000,0x000000,0x000000,0x000000,0x000000,0x000000,0x000000,0x000000,0x000000,0x000000,0x000000,0x000000,0x000000,0x000000,0x07f3fe,0x07f3fe,0x000000,0x000000,0x000000,0x000000,0x000000,0x000000,0x000000,0x000000,0x000000,0x000000,0x000000,0x000000,0x000000,0x000000,0x07f3fe,0x07f3fe,0x000000,0x000000,0x000000,0x000000,0x000000,0x000000,0x000000,0x000000,0x000000,0x000000,0x000000,0x000000,0x000000,0x000000,0x07f3fe,0x07f3fe,0x000000,0x000000,0x000000,0x000000,0x000000,0x000000,0x000000,0x000000,0x000000,0x000000,0x000000,0x000000,0x000000,0x000000,0x07f3fe,0x07f3fe,0x000000,0x000000,0x000000,0x000000,0x000000,0x000000,0x000000,0x000000,0x000000,0x000000,0x000000,0x000000,0x000000,0x000000,0x07f3fe,0x07f3fe,0x000000,0x000000,0x000000,0x000000,0x000000,0x000000,0x000000,0x000000,0x000000,0x000000,0x000000,0x000000,0x000000,0x000000,0x07f3fe,0x07f3fe,0x000000,0x000000,0x000000,0x000000,0x000000,0x000000,0x000000,0x000000,0x000000,0x000000,0x000000,0x000000,0x000000,0x000000,0x07f3fe,0x07f3fe,0x000000,0x000000,0x000000,0x000000,0x000000,0x000000,0x000000,0x000000,0x000000,0x000000,0x000000,0x000000,0x000000,0x000000,0x07f3fe,0x07f3fe,0x000000,0x000000,0x000000,0x000000,0x000000,0x000000,0x000000,0x000000,0x000000,0x000000,0x000000,0x000000,0x000000,0x000000,0x07f3fe,0x07f3fe,0x000000,0x000000,0x000000,0x000000,0x000000,0x000000,0x000000,0x000000,0x000000,0x000000,0x000000,0x000000,0x000000,0x000000,0x07f3fe,0x07f3fe,0x07f3fe,0x07f3fe,0x07f3fe,0x07f3fe,0x07f3fe,0x07f3fe,0x07f3fe,0x07f3fe,0x07f3fe,0x07f3fe,0x07f3fe,0x07f3fe,0x07f3fe,0x07f3fe,0x07f3fe},
	{0x07f3fe,0x000000,0x000000,0x000000,0x000000,0x000000,0x000000,0x000000,0x000000,0x000000,0x000000,0x000000,0x000000,0x000000,0x000000,0x07f3fe,0x000000,0x000000,0x000000,0x000000,0x000000,0x000000,0x000000,0x000000,0x000000,0x000000,0x000000,0x000000,0x000000,0x000000,0x000000,0x000000,0x000000,0x000000,0x000000,0x000000,0x000000,0x000000,0x000000,0x000000,0x000000,0x000000,0x000000,0x000000,0x000000,0x000000,0x000000,0x000000,0x000000,0x000000,0x000000,0x000000,0x000000,0x000000,0x000000,0x000000,0x000000,0x000000,0x000000,0x000000,0x000000,0x000000,0x000000,0x000000,0x000000,0x000000,0x000000,0x000000,0x000000,0x000000,0x000000,0x000000,0x000000,0x000000,0x000000,0x000000,0x000000,0x000000,0x000000,0x000000,0x000000,0x000000,0x000000,0x000000,0x000000,0x000000,0x000000,0x000000,0x000000,0x000000,0x000000,0x000000,0x000000,0x000000,0x000000,0x000000,0x000000,0x000000,0x000000,0x000000,0x000000,0x000000,0x000000,0x000000,0x000000,0x000000,0x000000,0x000000,0x000000,0x000000,0x000000,0x000000,0x000000,0x000000,0x000000,0x000000,0x000000,0x000000,0x000000,0x000000,0x000000,0x000000,0x000000,0x000000,0x000000,0x000000,0x000000,0x000000,0x000000,0x000000,0x000000,0x000000,0x000000,0x000000,0x000000,0x000000,0x000000,0x000000,0x000000,0x000000,0x000000,0x000000,0x000000,0x000000,0x000000,0x000000,0x000000,0x000000,0x000000,0x000000,0x000000,0x000000,0x000000,0x000000,0x000000,0x000000,0x000000,0x000000,0x000000,0x000000,0x000000,0x000000,0x000000,0x000000,0x000000,0x000000,0x000000,0x000000,0x000000,0x000000,0x000000,0x000000,0x000000,0x000000,0x000000,0x000000,0x000000,0x000000,0x000000,0x000000,0x000000,0x000000,0x000000,0x000000,0x000000,0x000000,0x000000,0x000000,0x000000,0x000000,0x000000,0x000000,0x000000,0x000000,0x000000,0x000000,0x000000,0x000000,0x000000,0x000000,0x000000,0x000000,0x000000,0x000000,0x000000,0x000000,0x000000,0x000000,0x000000,0x000000,0x000000,0x000000,0x000000,0x000000,0x000000,0x000000,0x000000,0x000000,0x000000,0x000000,0x000000,0x000000,0x000000,0x000000,0x000000,0x000000,0x000000,0x000000,0x000000,0x000000,0x000000,0x000000,0x000000,0x000000,0x000000,0x000000,0x000000,0x000000,0x000000,0x000000,0x07f3fe,0x000000,0x000000,0x000000,0x000000,0x000000,0x000000,0x000000,0x000000,0x000000,0x000000,0x000000,0x000000,0x000000,0x000000,0x07f3fe},
	{0x07f3fe,0x000000,0x000000,0x000000,0x000000,0x000000,0x000000,0x000000,0x000000,0x000000,0x000000,0x000000,0x000000,0x000000,0x000000,0x07f3fe,0x000000,0x000000,0x000000,0x000000,0x000000,0x000000,0x000000,0x000000,0x000000,0x000000,0x000000,0x000000,0x000000,0x000000,0x000000,0x000000,0x000000,0x000000,0x000000,0x000000,0x000000,0x000000,0x000000,0x000000,0x000000,0x000000,0x000000,0x000000,0x000000,0x000000,0x000000,0x000000,0x000000,0x000000,0x000000,0x000000,0x000000,0x000000,0x000000,0x000000,0x000000,0x000000,0x000000,0x000000,0x000000,0x000000,0x000000,0x000000,0x000000,0x000000,0x000000,0x000000,0x000000,0x000000,0x000000,0x000000,0x000000,0x000000,0x000000,0x000000,0x000000,0x000000,0x000000,0x000000,0x000000,0x000000,0x000000,0x000000,0x000000,0x000000,0x000000,0x000000,0x000000,0x000000,0x000000,0x000000,0x000000,0x000000,0x000000,0x000000,0x000000,0x000000,0x000000,0x000000,0x000000,0x000000,0x000000,0x000000,0x000000,0x000000,0x000000,0x000000,0x000000,0x000000,0x000000,0x000000,0x000000,0x000000,0x000000,0x000000,0x000000,0x000000,0x000000,0x000000,0x000000,0x000000,0x000000,0x000000,0x000000,0x000000,0x000000,0x000000,0x000000,0x000000,0x000000,0x000000,0x000000,0x000000,0x000000,0x000000,0x000000,0x000000,0x000000,0x000000,0x000000,0x000000,0x000000,0x000000,0x000000,0x000000,0x000000,0x000000,0x000000,0x000000,0x000000,0x000000,0x000000,0x000000,0x000000,0x000000,0x000000,0x000000,0x000000,0x000000,0x000000,0x000000,0x000000,0x000000,0x000000,0x000000,0x000000,0x000000,0x000000,0x000000,0x000000,0x000000,0x000000,0x000000,0x000000,0x000000,0x000000,0x000000,0x000000,0x000000,0x000000,0x000000,0x000000,0x000000,0x000000,0x000000,0x000000,0x000000,0x000000,0x000000,0x000000,0x000000,0x000000,0x000000,0x000000,0x000000,0x000000,0x000000,0x000000,0x000000,0x000000,0x000000,0x000000,0x000000,0x000000,0x000000,0x000000,0x000000,0x000000,0x000000,0x000000,0x000000,0x000000,0x000000,0x000000,0x000000,0x000000,0x000000,0x000000,0x000000,0x000000,0x000000,0x000000,0x000000,0x000000,0x000000,0x000000,0x000000,0x000000,0x000000,0x000000,0x000000,0x000000,0x000000,0x000000,0x000000,0x000000,0x000000,0x000000,0x000000,0x07f3fe,0x000000,0x000000,0x000000,0x000000,0x000000,0x000000,0x000000,0x000000,0x000000,0x000000,0x000000,0x000000,0x000000,0x000000,0x07f3fe},
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
